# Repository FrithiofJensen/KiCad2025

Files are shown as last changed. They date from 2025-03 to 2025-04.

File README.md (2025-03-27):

# KiCad 2025 - Fra schematic til PCB til ESP-NOW RC System

Velkommen til materialerne for KiCad 2025 seminaret afholdt af Gert Lauritsen. Dette repository indeholder eksempler, projektfiler og Arduino-kode specifikt fokuseret på design af et printkort (PCB) til et fjernstyringssystem (RC) baseret på ESP-NOW protokollen.

Formålet med seminaret er at demonstrere designflowet i KiCad – fra skematisk diagram til færdigt PCB-layout – med et konkret projekt som eksempel: design af hardware til en ESP-NOW baseret sender eller modtager.

Vi vil se på, hvordan man designer et printkort, der integrerer en ESP32 microcontroller sammen med nødvendige komponenter som f.eks. input-enheder (joysticks, knapper) til en sender, eller output-drivere (servo-stik, motor-drivere) til en modtager. De medfølgende `.ino` filer implementerer selve ESP-NOW kommunikationen.

## Indhold

Repository'et indeholder (eller vil indeholde) følgende:

*   **KiCad Projektfiler:**
    *   Eksempler på skematiske diagrammer (`.kicad_sch`) for en RC-sender og/eller modtager.
    *   Eksempler på PCB layouts (`.kicad_pcb`) tilpasset ESP-moduler og RC-komponenter.
    *   Projektfil (`.kicad_pro`).
*   **Biblioteksfiler:**
    *   Specifikke symboler (`.kicad_sym`) og footprints (`.kicad_mod`) brugt i eksemplerne (hvis de ikke er standard i KiCad).
*   **ESP-NOW RC Arduino Sketches (`.ino`):**
    *   `RcRemote.ino`: Kode til ESP32 **senderen**. Læser typisk inputs (f.eks. fra potentiometre/joystick på det designede PCB) og sender data via ESP-NOW.
    *   `RCModtager.ino`: Kode til ESP32 **modtageren**. Modtager data via ESP-NOW og styrer outputs (f.eks. servoer eller motorer, potentielt via det designede PCB).
    *   Disse filer er beregnet til at blive kompileret og uploadet via Arduino IDE til separate ESP32 boards.
*   **Gerber/Produktionsfiler (Eksempel):**
    *   Eksempler på output-filer (`.gbr`, `.drl`) til PCB-produktion.

## Forudsætninger

For at få det fulde udbytte af seminaret og materialerne anbefales følgende software og hardware:

*   **Software:**
    *   **KiCad:**  Den seneste stabile version anbefales. Kan downloades gratis fra [https://www.kicad.org/](https://www.kicad.org/).
    *   **Arduino IDE:** Nødvendig for at arbejde med `.ino` filerne. Kan downloades gratis fra [https://www.arduino.cc/en/software](https://www.arduino.cc/en/software).
        *   **VIGTIGT:** Sørg for at have **ESP8266** og/eller **ESP32 board support** installeret i Arduino IDE via "Boards Manager". Se guides online, f.eks.:
            *   ESP32: [Howto install ESP32](https://randomnerdtutorials.com/installing-esp32-arduino-ide-2-0/)
        *   Tjek `.ino` filerne for eventuelle yderligere nødvendige Arduino libraries (ud over ESP-NOW, som er indbygget) og installer dem via "Library Manager".
*   **Hardware:**
    *   **Mindst to ESP32 boards** (f.eks. NodeMCU, ESP32 DevKitC) – ét til senderen og ét til modtageren for at kunne teste ESP-NOW kommunikationen.
    *   (Valgfrit) Komponenter til at bygge prototyper af sender/modtager (breadboard, ledninger, joysticks, potentiometre, servoer etc.).

## Brug af Materialerne

1.  **Klon eller Download:** Hent materialerne ned på din computer ved at klone repository'et (`git clone https://github.com/gert-lauritsen/KiCad2025.git`) eller downloade det som en ZIP-fil.
2.  **KiCad:** Åbn `.kicad_pro` filen i KiCad for at udforske skematik og PCB layout. Brug filerne som reference eller udgangspunkt for dit eget RC-hardware design.
3.  **Arduino / ESP-NOW:**
    *   Åbn `RcRemote.ino` i Arduino IDE.
    *   Åbn `RCModtager.ino` i et andet Arduino IDE vindue (eller efter hinanden).
    *   **Vigtigt:** ESP-NOW kræver, at enhederne kender hinandens MAC-adresser. Du skal typisk finde MAC-adressen på modtager-boardet og indsætte den i koden på sender-boardet (og/eller omvendt, afhængigt af koden). Find instruktioner til dette i kode-kommentarerne eller i ESP-NOW tutorials.
    *   Vælg det korrekte ESP32 board og port i "Tools" menuen for hvert board.
    *   Kompilér og upload sender-koden til det ene board.
    *   Kompilér og upload modtager-koden til det andet board.
    *   Test kommunikationen. Brug evt. Serial Monitor til debugging.

Vi håber, du får et lærerigt og udbytterigt seminar! Husk at installere KiCad, Arduino IDE og ESP board support *inden* seminaret starter for at få mest muligt ud af det.

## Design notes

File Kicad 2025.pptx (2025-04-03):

## Kicad

Vejen til nemmere PCB design

## Gert Lauritsen

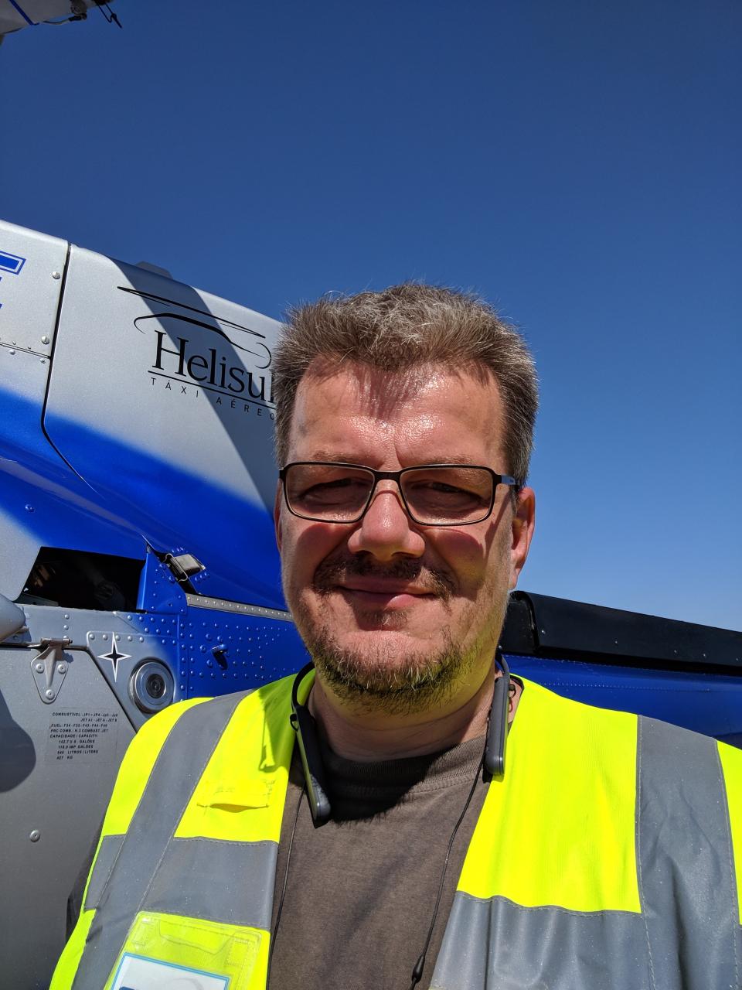
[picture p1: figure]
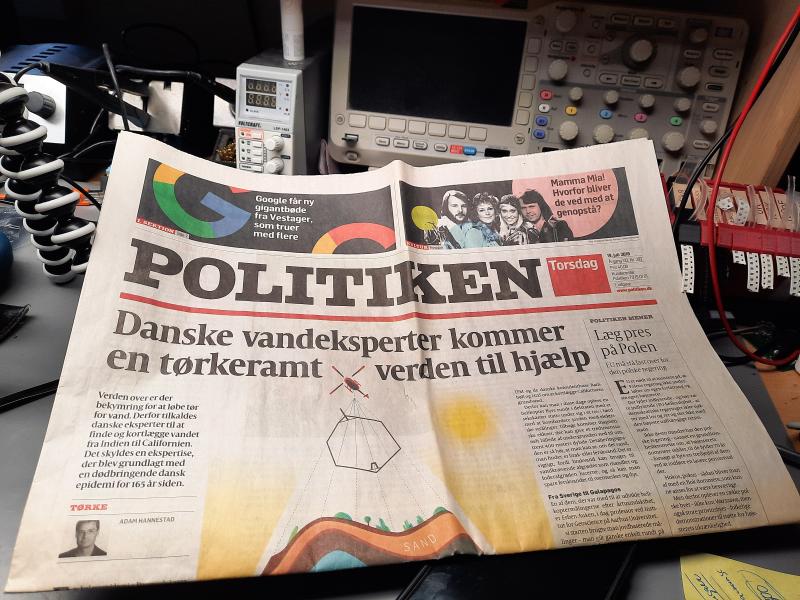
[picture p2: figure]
Et billede, der indeholder tekst, avis, Publikation/tidsskrift/artikel, Avis

- BENG Digital Electronic
- Medskifter af Skytem
- SW&HW udvikler
- Brygger ØL
- 3 børn, kone, hus og Ford

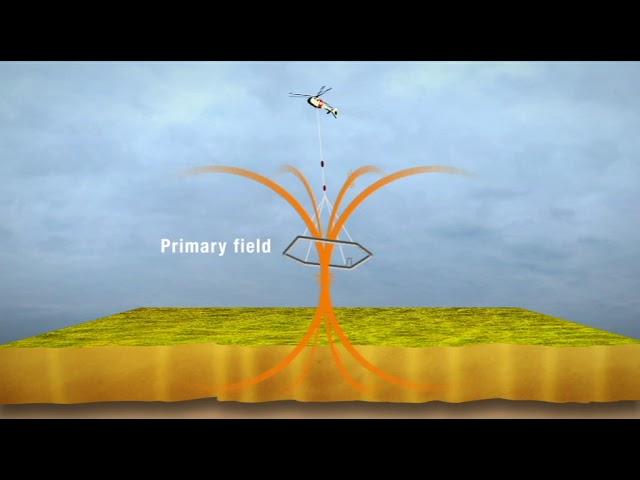
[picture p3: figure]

https://www.youtube.com/watch?v=AwNg--LtuMc

## Agenda

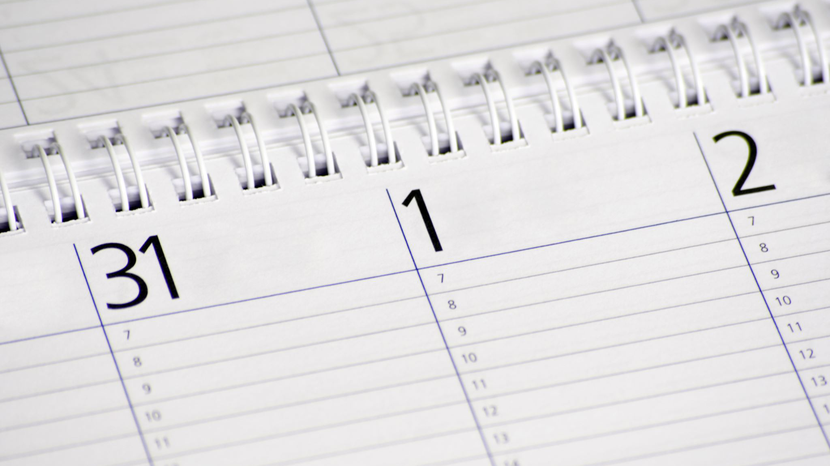
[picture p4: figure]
En side i en planner

- Diagramopsætning
- Gennemgang af fjernbetjenning
- Layout editor
- Gennemgang af Layout
- 3D-visning
- ESP32
  - Serial
  - GPIO
  - ESPnow
  - Gennemgang af RC program

## Åbning af eksistrende projekt

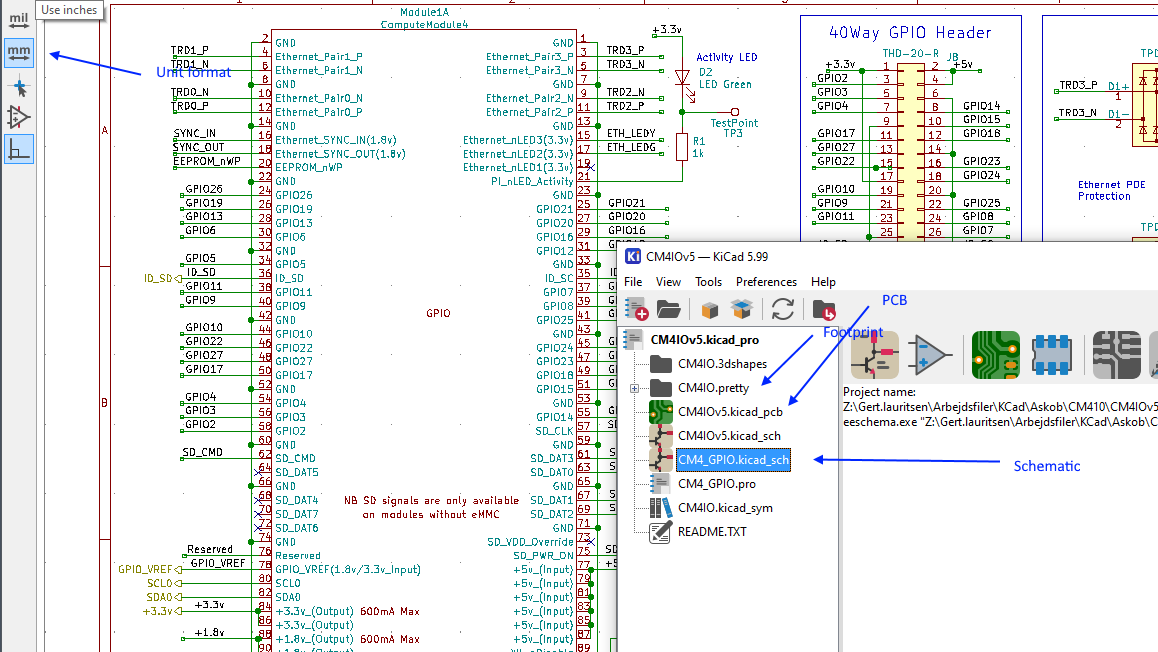
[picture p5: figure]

- Schematic
- PCB

## PlacePart

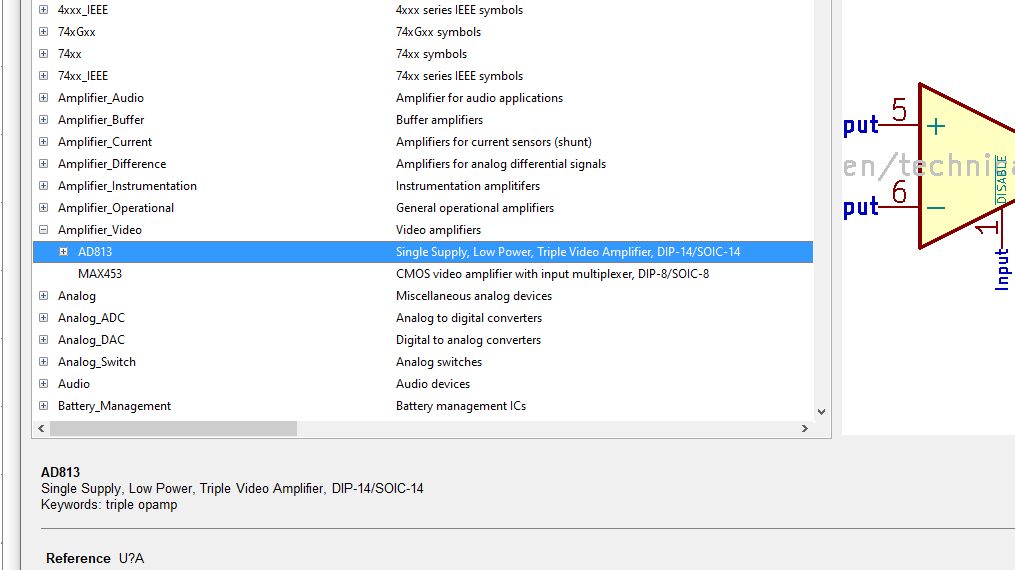
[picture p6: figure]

- Shift+A
- Søg både på part og beskrivelse
- Rotation r/y
- Datablad linket påkomponent
- Part propertry
- Eksterne Library (digikey/mouser)

## Symboler

Power objekter/symboler [P]
Hieraki porte
Globale Nets
Lokale Net
Symboler repræsentere ikke komponeter

## Opgave Tegn følgende skematic

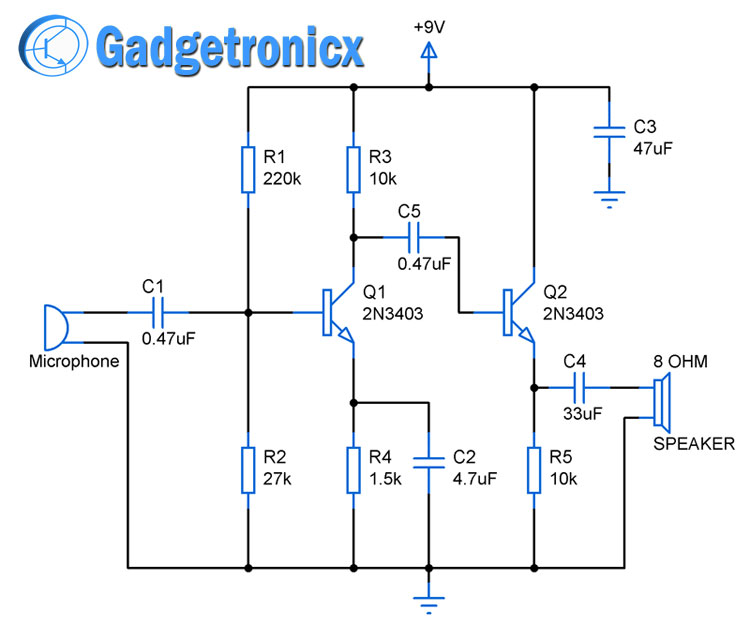
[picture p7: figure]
2-stage-amplifier-circuit-diagram

## Hierarkisk design

- Opret sheet
- Gå ind I sheet
- Export porte

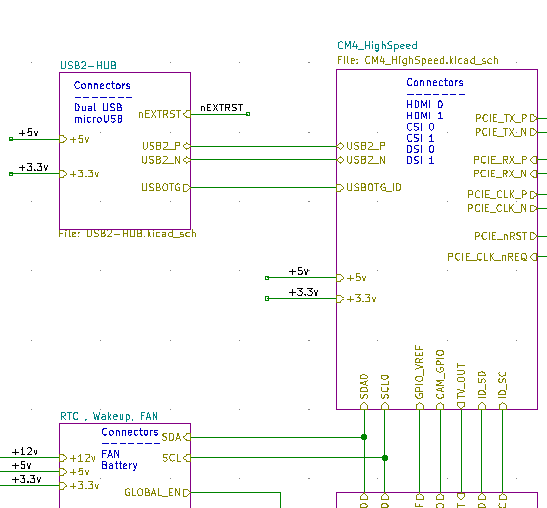
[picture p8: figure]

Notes: Present sensor

## Footprint/netliste

- Annotate
- Place footprint

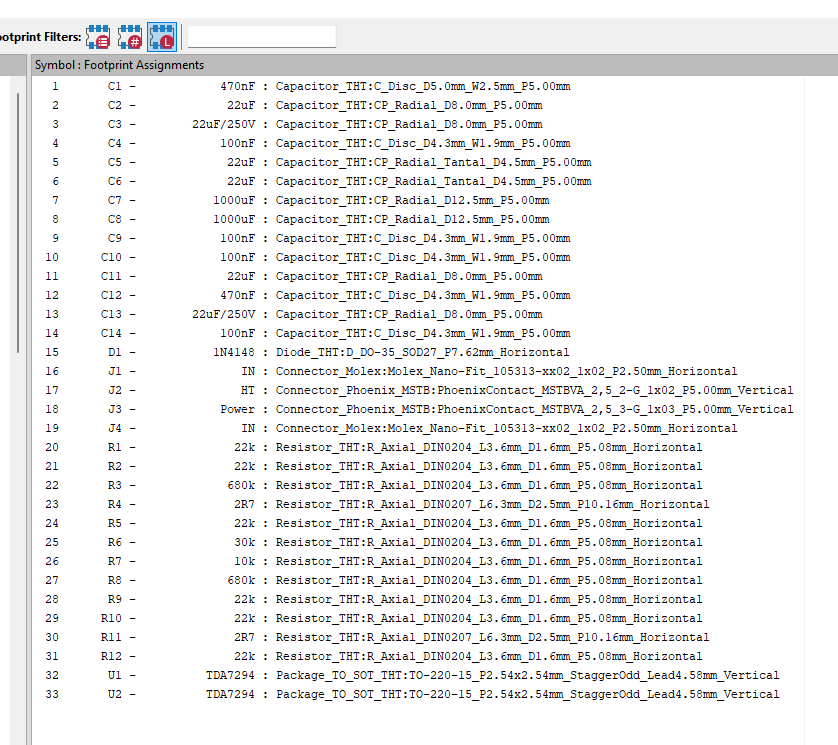
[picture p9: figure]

## Lib Symboler

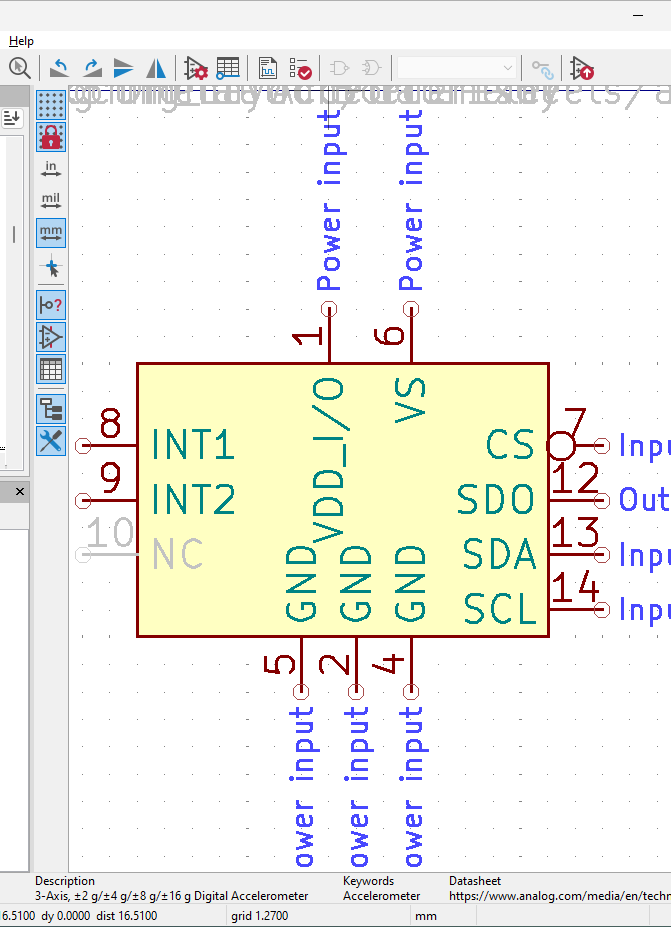
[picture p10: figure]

- Lib Editor

## Layout editor

- Gennemgang af funktioner
- Placement
- Check af footprint

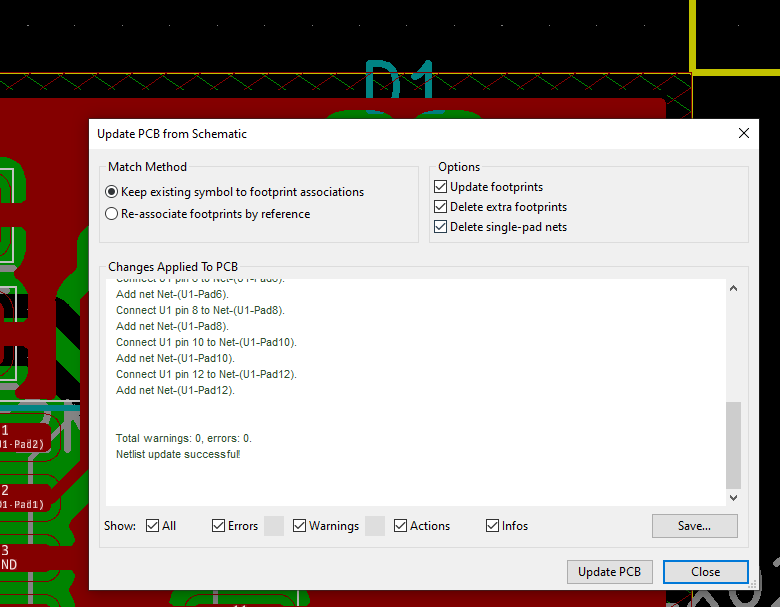
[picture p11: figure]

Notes: Wirenet
Sammenkædning af sch og PCB

## 3D-visning

- Mekanik
- Layer

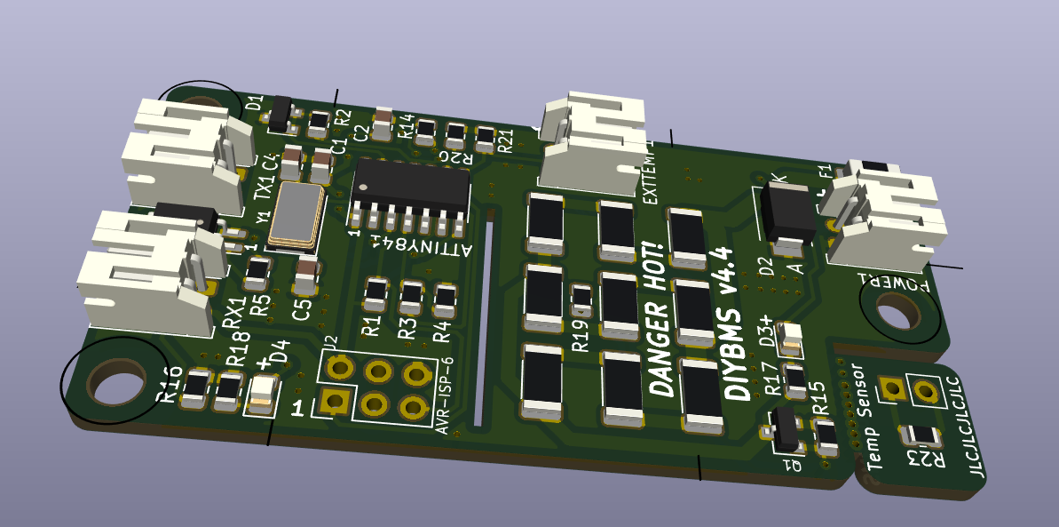
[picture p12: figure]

## Opgave PCB routing

- Route det første schematic til PCB

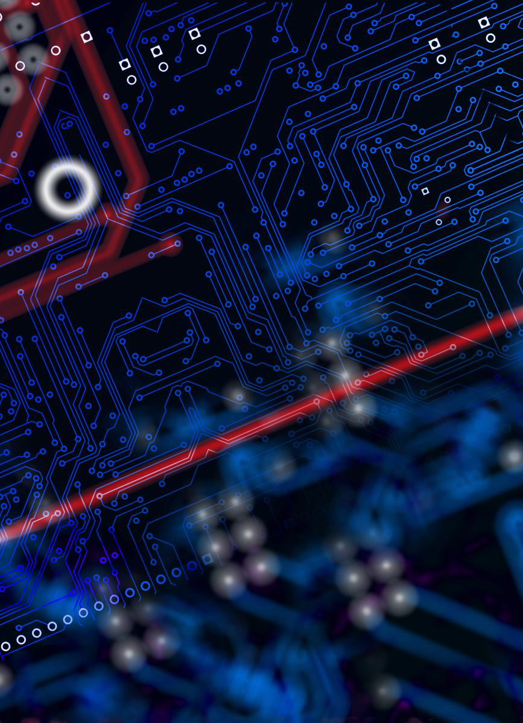
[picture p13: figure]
Elektronisk kredsløbskort

## Hierarkisk Design

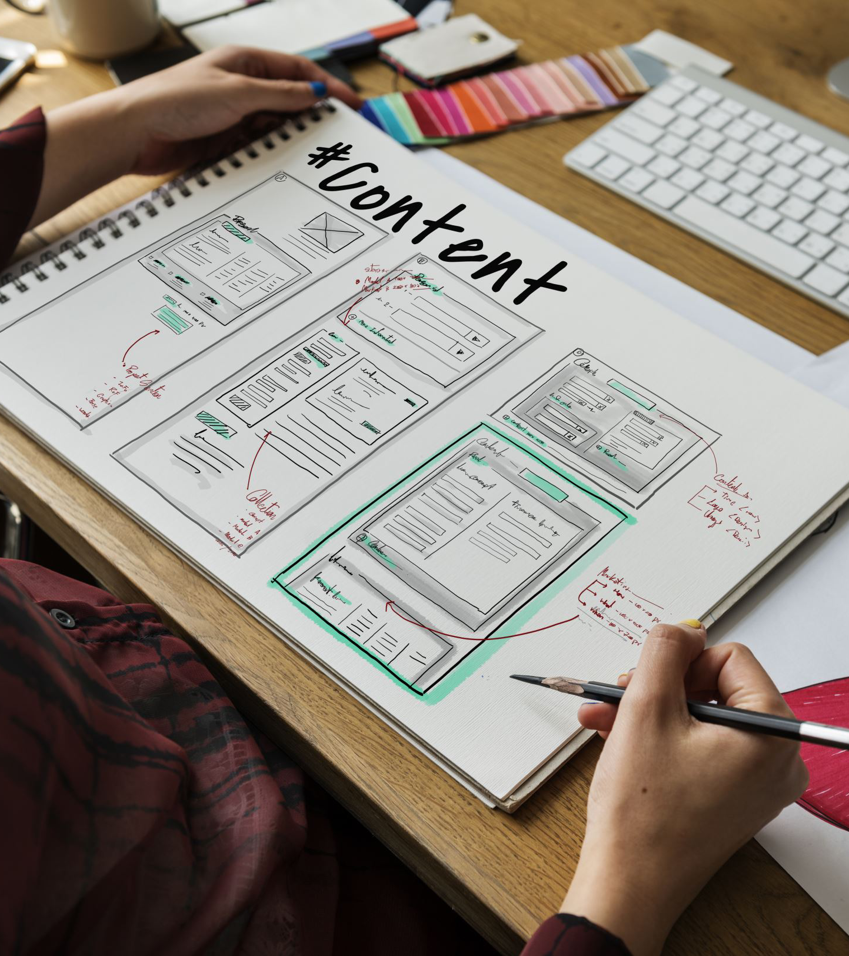
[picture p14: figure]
Person, der skriver i en notesblok

- Hvorfor skal vi tegne hierarksik
  - Class, nedavning, reuse

## Software

Sender/modtager
Serial
GPIO/Analog input
ESPNow
Remote PWM control

## Bootmode

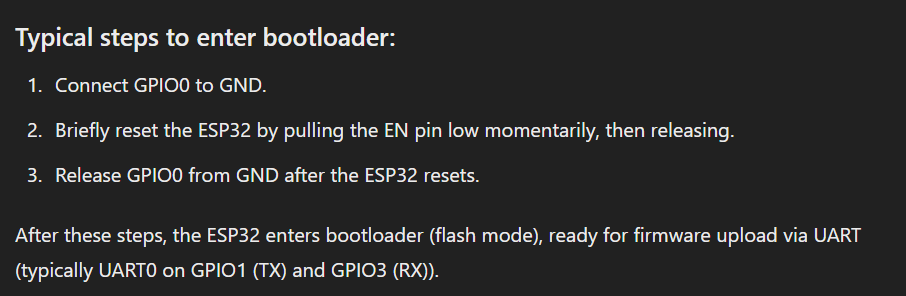
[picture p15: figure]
Et billede, der indeholder tekst, skærmbillede, Font/skrifttype Indhold genereret af kunstig intelligens kan være forkert.
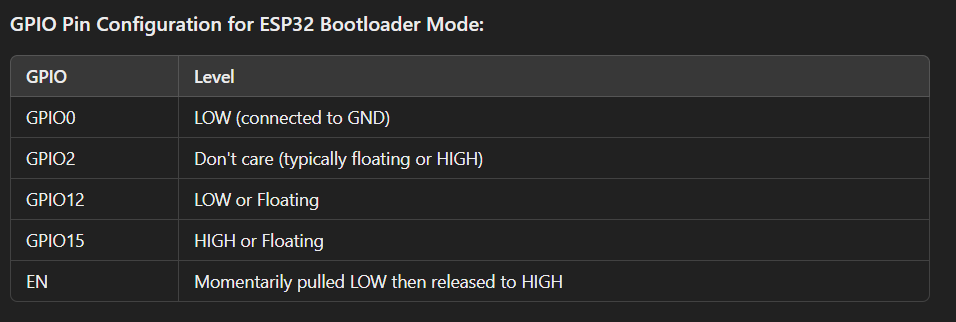
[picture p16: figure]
Et billede, der indeholder tekst, skærmbillede, software, Font/skrifttype Indhold genereret af kunstig intelligens kan være forkert.

## Boot Errors

- PSRAM
- No core dump

E (709) quad_psra: PSRAM ID read error: 0x00ffffff, PSRAM chip not found or not supported

Profil:

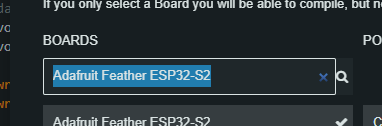
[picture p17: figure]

E (843) esp_core_dump_flash: No core dump partition found!

E (843) esp_core_dump_flash: No core dump partition found!

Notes: https://docs.espressif.com/projects/esptool/en/latest/esp32/advanced-topics/boot-mode-selection.html

## GPIO/Analog input

GPIO - De Digitale Schweizerknive (GPIO: Står for General Purpose Input/Output)
GPIO Funktioner (Primære):
- Digital Input (INPUT):
- Læser en digital tilstand: HØJ (typisk ~3.3V) eller LAV (typisk ~0V / GND).
- Bruges til knapper, simple sensorer (f.eks. bevægelsessensor), signal fra andre enheder.
- Kan ofte konfigureres med INPUT_PULLUP (intern modstand til 3.3V) eller INPUT_PULLDOWN (intern modstand til GND) for at sikre en stabil tilstand, når intet er tilsluttet.
Digital Output (OUTPUT):
- Sætter en digital tilstand: HØJ (3.3V) eller LAV (GND).
- Bruges til at tænde/slukke LEDs, styre relæer (via transistor), sende simple signaler.

## GPIO/Analog input

Analog Input - Måling af Kontinuerlige Værdier
- Hvad er det? Evnen til at måle en kontinuert spænding (inden for et bestemt område) i stedet for kun HØJ/LAV.
ADC: Foregår via en Analog-to-Digital Converter (ADC) indbygget i ESP32.
- Anvendelse: Læsning af potentiometre, lyssensorer (LDR), analoge temperatursensorer, joysticks, etc.
ESP32 ADC Specifikationer:
- Hardware: ESP32 har typisk to ADCs (ADC1 og ADC2).
- Opløsning: Standard er 12-bit. Dette betyder, at ADC'en kan repræsentere spændingen som en digital værdi mellem 0 og 4095.
Arduino IDE Funktioner:
- pinMode(pin, MODE); // Sætter pin til INPUT, OUTPUT, INPUT_PULLUP etc.
- digitalRead(pin); // Læser digital værdi (HIGH/LOW).
- digitalWrite(pin, VALUE); // Skriver digital værdi (HIGH/LOW).
- analogRead(pin); // Læser analog værdi (0-4095).

VIGTIGT: ADC2 & Wi-Fi: Pins tilsluttet ADC2 kan IKKE bruges til analog læsning, mens Wi-Fi er aktivt!
Brug primært pins på ADC1 (f.eks. GPIO 1-10) hvis du også bruger Wi-Fi.
ADC2 finds ikke på ESP32-S2

## ESP Serial Kommunikation (UART)

- Pins: Bruger primært to pins:
- TX (Transmit): Sender data fra ESP'en.
- RX (Receive): Modtager data til ESP'en.
På ESP32 (Arduino IDE):
- Serial Objektet: Standard seriel port, typisk forbundet til USB-porten via en onboard USB-til-UART chip. Bruges til:
- Programmering/Flashing.
- Debugging via Arduino IDE's "Serial Monitor".
- Ekstra Porte (Serial1, Serial2): ESP32 har flere uafhængige hardware UART-porte, som kan mappes til (næsten) valgfri GPIO pins til kommunikation med andre enheder (sensorer, GPS, osv.).
Vigtige Funktioner:
- Serial.begin(baud_rate); // Starter kommunikationen med specificeret hastighed.
- Serial.print("Tekst"); // Sender tekst.
- Serial.println(value); // Sender værdi og linjeskift.
- Serial.available(); // Tjekker om der er data klar til at blive læst.
- Serial.read(); // Læser ét byte af modtaget data.
Typiske Anvendelser:
✅ Debugging: Nemmeste måde at få information ud fra din ESP32 under kørsel.
✅ Programmering: Standardmetoden til at uploade kode.
✅ Kommunikation med PC: Simple kontrol-interfaces eller dataopsamling.
✅ Kommunikation med Perifere Enheder: GPS moduler, visse sensorer, andre microcontrollere.

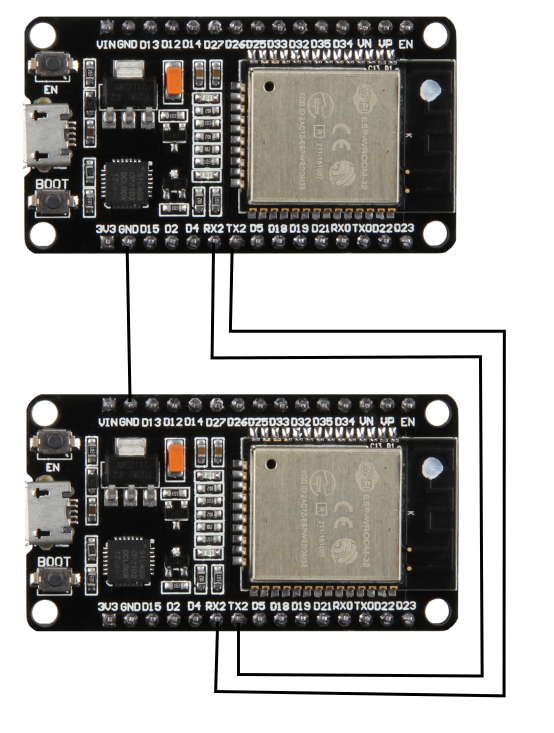
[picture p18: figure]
Problems with using Serial2 communication between 2 esp32 - Programming - Arduino Forum

## Serial Opgave

- Få din ESP32 til at skrive klokken.
- Hvis der er tid, så connect til NTP
- // --- NTP Settings --- const char* ntpServer1 = "pool.ntp.org"; const char* ntpServer2 = "time.nist.gov"; // Optional backup server

## ESPNow

Hvad er ESP-NOW?
- En kommunikationsprotokol udviklet af Espressif (firmaet bag ESP32/ESP8266).
- Tillader direkte (peer-to-peer) kommunikation mellem ESP-enheder.
- Bruger ikke et traditionelt Wi-Fi netværk (ingen router/AP nødvendig).
Hvordan Virker Det?
- MAC Adresser: Enheder identificerer hinanden vha. deres unikke MAC-adresse (ligesom et "device ID").
- Forbindelsesløs: Sender data uden først at etablere en formel forbindelse (ligesom UDP, men simplere). Ingen "handshake".
- Korte Pakker: Sender små datapakker (op til 250 bytes).
- Callbacks: Bruger funktioner (callbacks) til at vide, hvornår data er sendt succesfuldt, eller hvornår data er modtaget.
Vigtigste Fordele:
- ✅ Hurtigt: Meget lav forsinkelse (latency) – data sendes næsten øjeblikkeligt.
- ✅ Lavt Strømforbrug: Effektivt, da der ikke opretholdes en konstant Wi-Fi forbindelse. Godt til batteridrevne enheder.
- ✅ Simpelt: Nemmere at sætte op end fuld Wi-Fi-forbindelse eller Bluetooth.
- ✅ Pålideligt (kort afstand): God til stabil kommunikation over korte afstande.
Begrænsninger:
- Kort Rækkevidde: Ligesom almindelig Wi-Fi (typisk < 100m, afhængigt af omgivelser).
- Ikke Routbart: Kan ikke sende data direkte over internettet (kræver en "gateway" ESP, der er på Wi-Fi/Ethernet).
- Begrænset Data: Kun små datapakker ad gangen (max 250 bytes).
- Kun ESP: Virker kun mellem Espressif-chips (ESP32, ESP8266).
Typiske Anvendelser:
- Sensornetværk (mange sensorer sender til én central enhed).
- Fjernbetjeninger og trådløse knapper.
- Hurtig udveksling af status mellem enheder.
- Enkel styring af lys, relæer osv.
Konklusion:
ESP-NOW er ideelt til hurtig, lokal og strømbesparende kommunikation mellem ESP-enheder, hvor der ikke er behov for et fuldt Wi-Fi netværk eller internetadgang.

## ESPNow opgave

- Send et signal til din side maker, som tænder og slukker hans LED 1 gang/sekund
- Det må kun sendes til hans MAC adresse og ikke andre.
- Den anden laver modtageren

## Remote PWM control

Hvad er RC PWM?
- RC: Står for Radio Control (typisk brugt i hobby-modeller).
- PWM: Pulse Width Modulation. En digital måde at repræsentere en analog værdi (f.eks. en position eller hastighed).
- RC PWM: En specifik type PWM-signal, der er standard inden for RC-hobbyen til at styre komponenter.
Hvordan Virker Det?
- Gentagende Puls: Signalet består af en puls, der gentages med en fast frekvens, typisk 50 Hz (dvs. én puls hvert 20. millisekund).
- Pulsens Bredde (Varighed): Det vigtige er, hvor længe pulsen er "høj" (typisk 3.3V eller 5V) inden for hver 20 ms cyklus. Denne varighed måles i mikrosekunder (µs).
Betydningen af Bredden:
- ~1000 µs (1.0 ms): Typisk minimum værdi (f.eks. servo helt til venstre, motor slukket).
- ~1500 µs (1.5 ms): Typisk center/neutral værdi (f.eks. servo i midten, motor stoppet/neutral).
- ~2000 µs (2.0 ms): Typisk maksimum værdi (f.eks. servo helt til højre, motor fuld gas).
Typiske Anvendelser:
- Servo Motorer: Pulsbredden bestemmer den vinkel, servoen skal dreje til.
- Electronic Speed Controllers (ESC'er): Pulsbredden bestemmer den hastighed (og retning), motoren skal køre med.

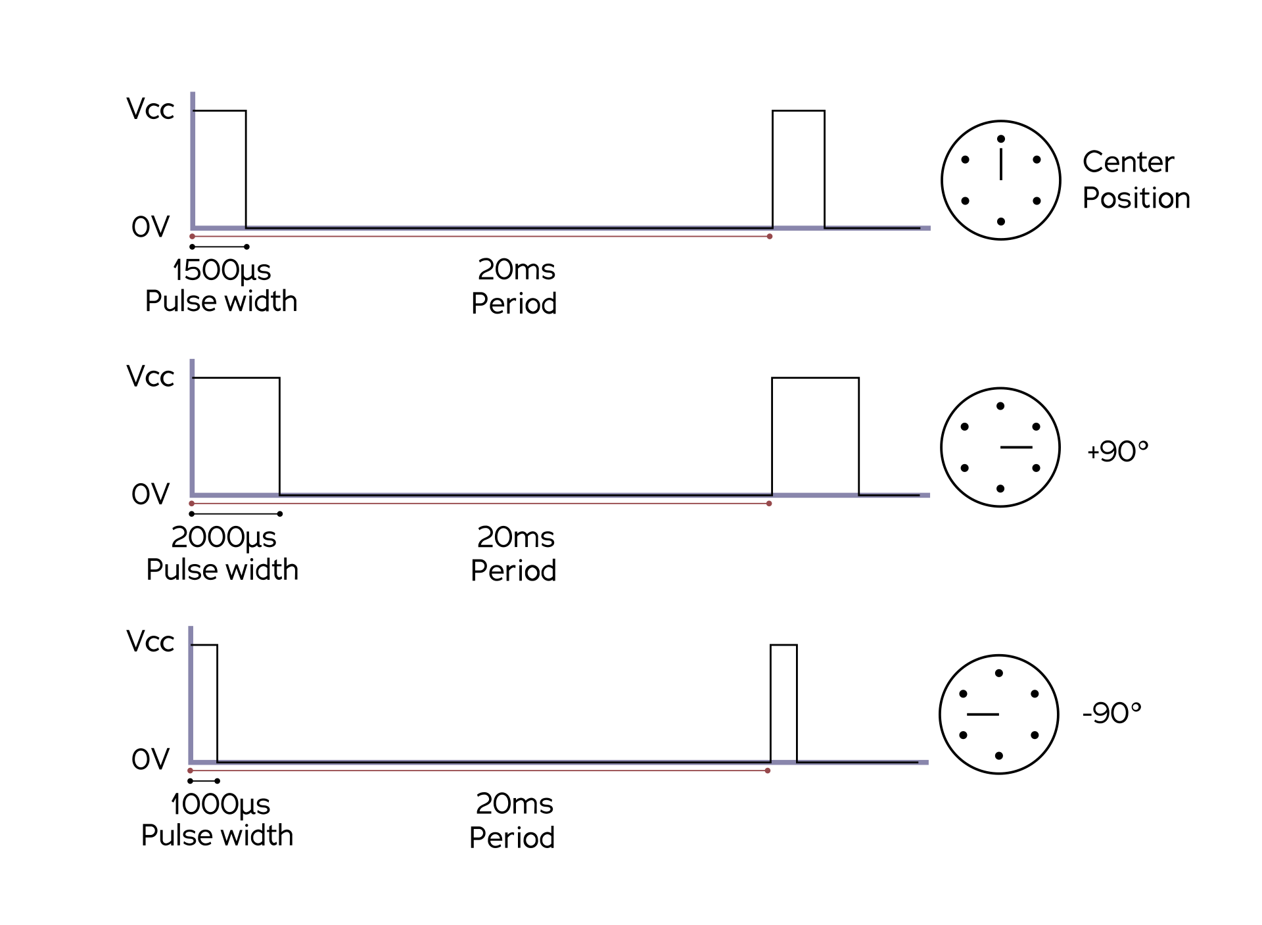
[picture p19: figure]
undefined

## Kina logik

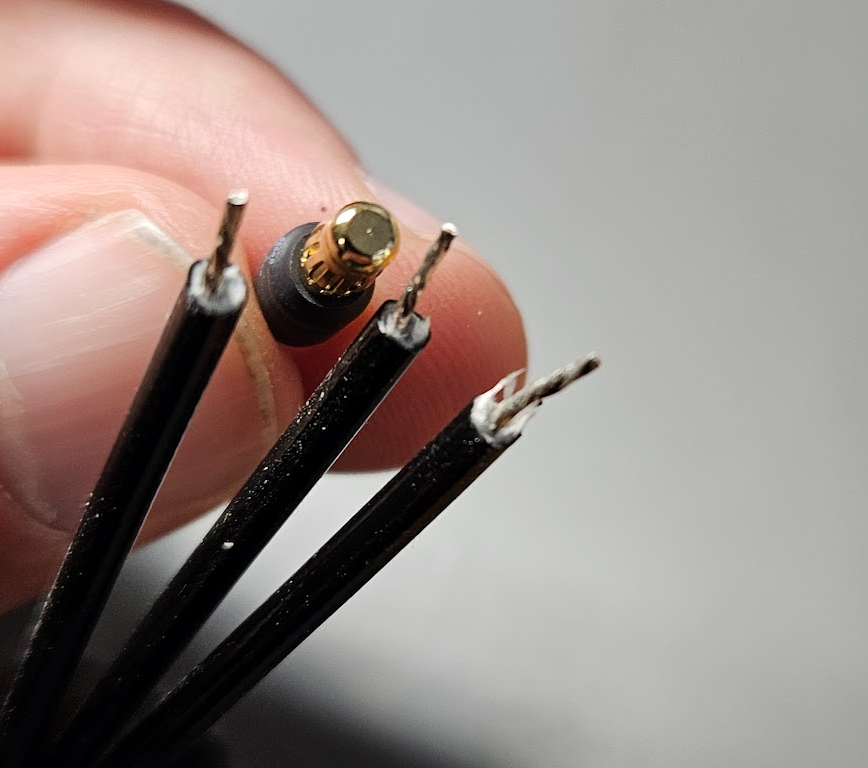
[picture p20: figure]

## Gennemgang af RC sender

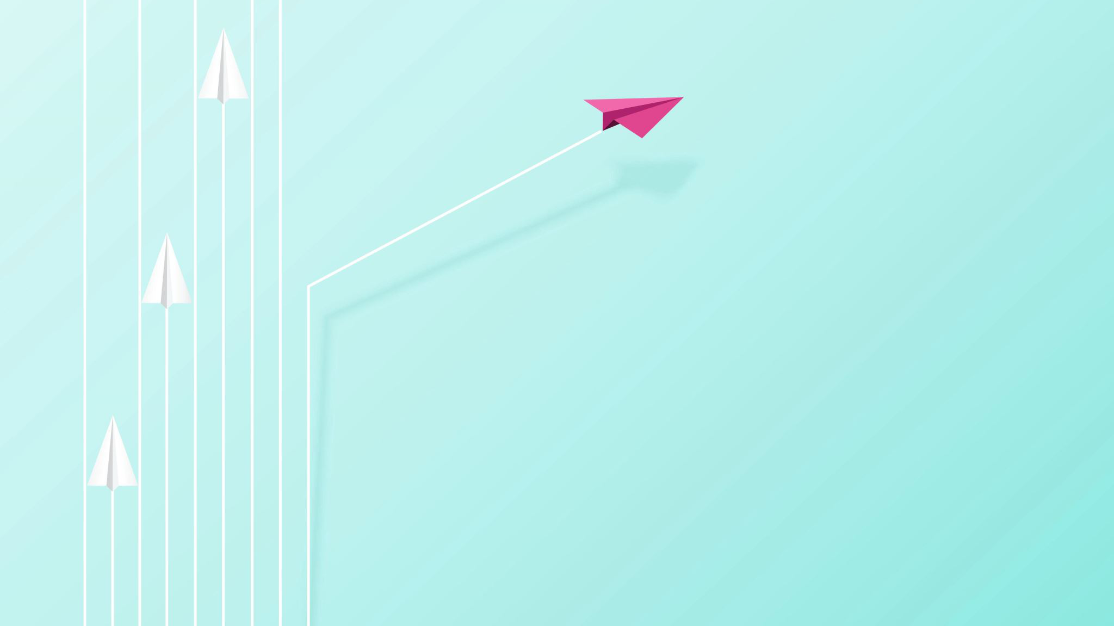
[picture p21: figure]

## Gennemgang af RC modtager

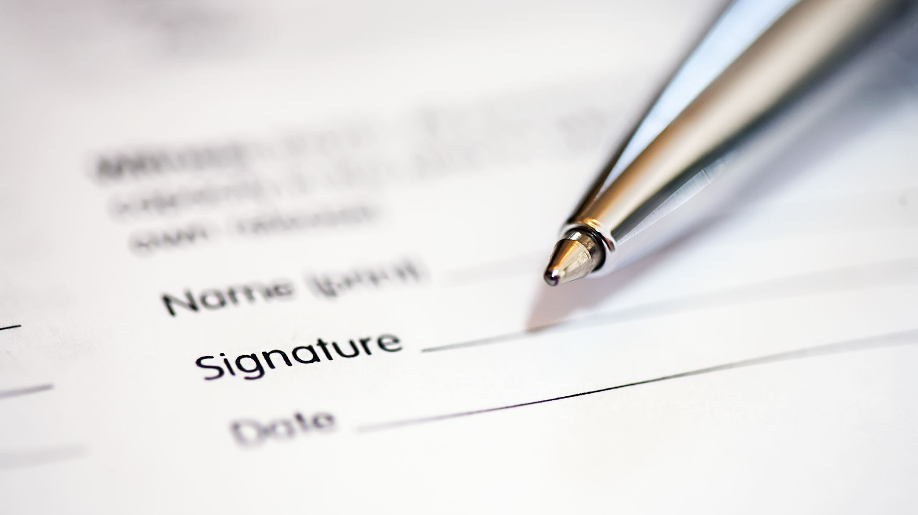
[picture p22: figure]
Pen, der er placeret oven på en signaturlinje

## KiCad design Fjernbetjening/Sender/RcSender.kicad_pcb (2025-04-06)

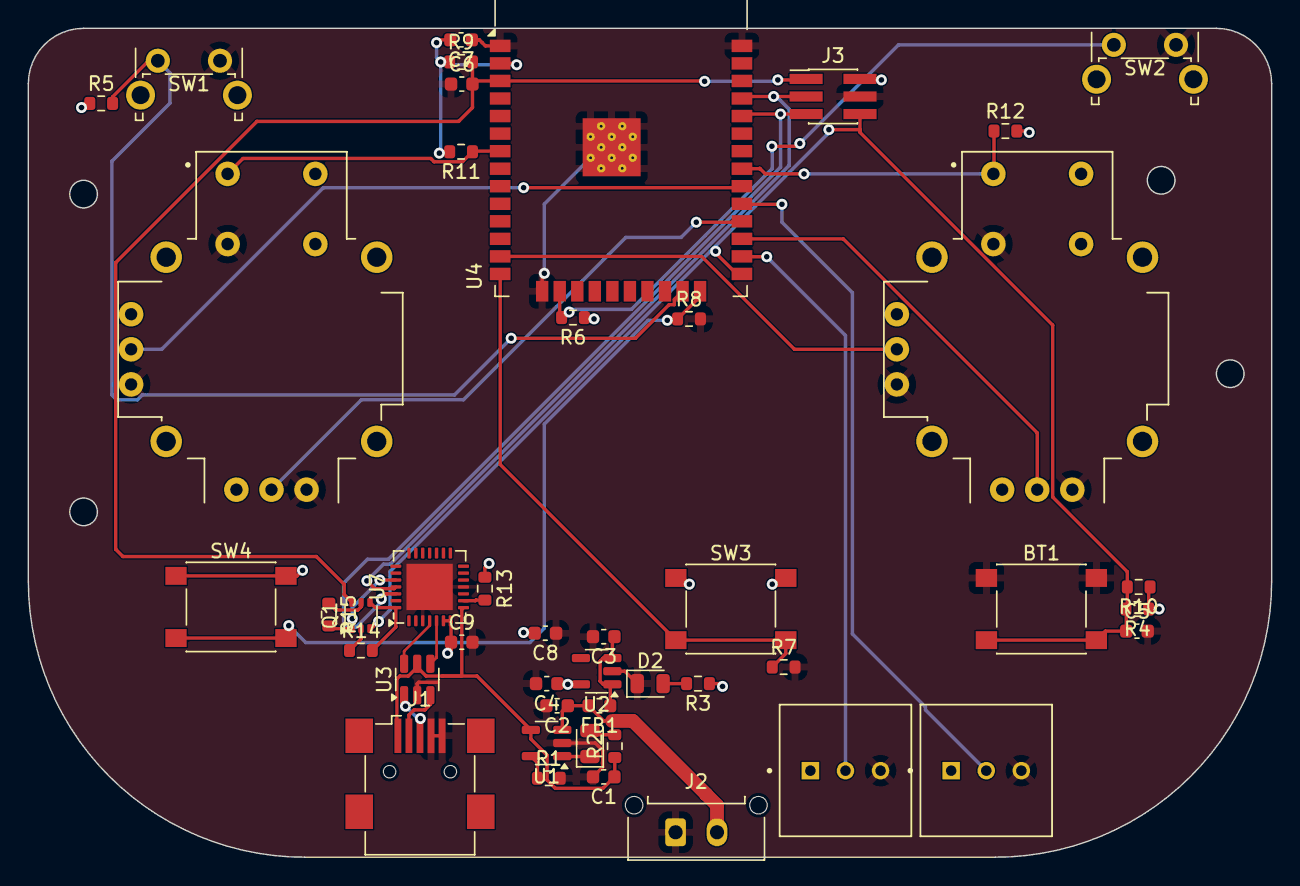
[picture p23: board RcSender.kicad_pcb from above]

Board: 2 copper layers, 90.0 x 60.0 mm, 45 parts (0 on the bottom side), 34 nets.

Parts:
BT1: SW_Push; SW_SPST_PTS645
C1, C3, C4: 1uF; C_0603_1608Metric
C2: 10nF; C_0603_1608Metric
C5, C6, C7, C8: 0.1uf; C_0603_1608Metric
C9: 10u; C_0603_1608Metric
D1: Chrg; LED_0805_2012Metric
D2: PWR ON; LED_0805_2012Metric
FB1: Ferrite Bead; L_0603_1608Metric
J1: USB_A; USB_Mini-B_Wuerth_65100516121_Horizontal
J2: Bat; Molex_Micro-Fit_3.0_43650-0215_1x02_P3.00mm_Vertical
J3: Prog; PinHeader_2x03_P1.27mm_Vertical_SMD
POT1, POT2: COM-09806; POT-COM_09806
Q1: BC846BS; SOT-363_SC-70-6
R1: 2k; R_0603_1608Metric
R2, R3: 330; R_0603_1608Metric
R4, R5, R6, R7, R8, R11, R12: 4.7k; R_0603_1608Metric
R9, R10: 10K; R_0603_1608Metric
R13: 1k; R_0603_1608Metric
R14, R15: 10k; R_0603_1608Metric
SW1, SW2: SW_Push; SW_Tactile_SPST_Angled_PTS645Vx39-2LFS
SW3, SW4: SW_Push; SW_SPST_PTS645
U1: MCP73832-2-OT; SOT-23-5
U2: AP2112K-3.3; SOT-23-5
U3: USBLC6-2SC6; SOT-23-6
U4: ESP32-WROOM-32
U5, U6: COM-09032; POT-COM-09032
U7: CP2102N-Axx-xQFN28; QFN-28-1EP_5x5mm_P0.5mm_EP3.35x3.35mm

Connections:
+3.3V: C4.1, C7.2, C8.2, C9.1, J3.2, POT1.1, POT2.1, R3.1, R4.1, R5.1, R6.1, R9.1, R10.1, R11.2, R12.2, R13.1, SW3.1, SW4.1, U2.5 (VOUT), U4.2 (VDD), U5.H1 (H+), U5.V1 (V+), U6.H1 (H+), U6.V1 (V+), U7.6 (VDD), U7.7 (VREGIN)
+5V: C1.1, J1.1 (VBUS), R2.1, U1.4 (V_{DD}), U3.5 (VBUS), U7.8 (VBUS)
BT: BT1.2, C5.1, J3.6, Q1.3 (C2), R4.2, R10.2, U4.25 (IO0)
EN: C6.2, J3.1, Q1.6 (C1), R9.2, U4.3 (EN)
GND: BT1.1, C1.2, C2.2, C3.2, C4.2, C5.2, C6.1, C7.1, C8.1, C9.2, D2.1 (K), J1.4 (GND), J1.5 (Shield), J2.1, J3.4, POT1.3, POT2.3, R1.2, R7.2, R8.2, SW1.2, SW2.2, U1.2 (V_{SS}), U2.2 (GND), U3.2 (GND), U4.1 (GND), U4.15 (GND), U4.38 (GND), U4.39 (GND), U5.B2A (SEL-), U5.H3 (H-), U5.V3 (V-), U6.B2A (SEL-), U6.H3 (H-), U6.V3 (V-), U7.3 (GND), U7.11 (~SUSPEND), U7.29 (GND)
IO2: R8.1, SW4.2, U4.24 (IO2)
IO4: POT2.2, U4.26 (IO4)
IO5: POT1.2, U4.29 (IO5)
IO12: R7.1, SW3.2, U4.14 (IO12)
IO13: R6.2, SW2.1, U4.16 (IO13)
IO14: U4.13 (IO14), U6.V2 (V)
IO15: R5.2, SW1.1, U4.23 (IO15)
IO16: U4.27 (IO16), U6.H2 (H)
IO17: U4.28 (IO17), U5.H2 (H)
IO18: U4.30 (IO18), U5.V2 (V)
IO19: R12.1, U4.31 (IO19), U6.B1A (SEL+)
IO35: R11.1, U4.7 (IO35), U5.B1A (SEL+)
unnamed: D1.2 (A), R2.2
unnamed: D1.1 (K), U1.1 (STAT)
unnamed: D2.2 (A), R3.2
unnamed: J1.3 (D+), U3.1 (I/O1)
unnamed: J1.2 (D-), U3.3 (I/O2)
unnamed: Q1.2 (B1), R14.1
unnamed: Q1.1 (E1), R15.2, U7.24 (~RTS)
unnamed: Q1.5 (B2), R15.1
unnamed: Q1.4 (E2), R14.2, U7.28 (~DTR)
unnamed: R1.1, U1.5 (PROG)
unnamed: C3.1, FB1.1, U2.1 (VIN), U2.3 (EN)
unnamed: R13.2, U7.9 (~RST)
RX: J3.5, U4.34 (RXD0/IO3), U7.26 (TXD)
TX: J3.3, U4.35 (TXD0/IO1), U7.25 (RXD)
USBN: U3.4 (I/O2), U7.5 (D-)
USBP: U3.6 (I/O1), U7.4 (D+)
VIN: C2.1, FB1.2, J2.2, U1.3 (V_{BAT})

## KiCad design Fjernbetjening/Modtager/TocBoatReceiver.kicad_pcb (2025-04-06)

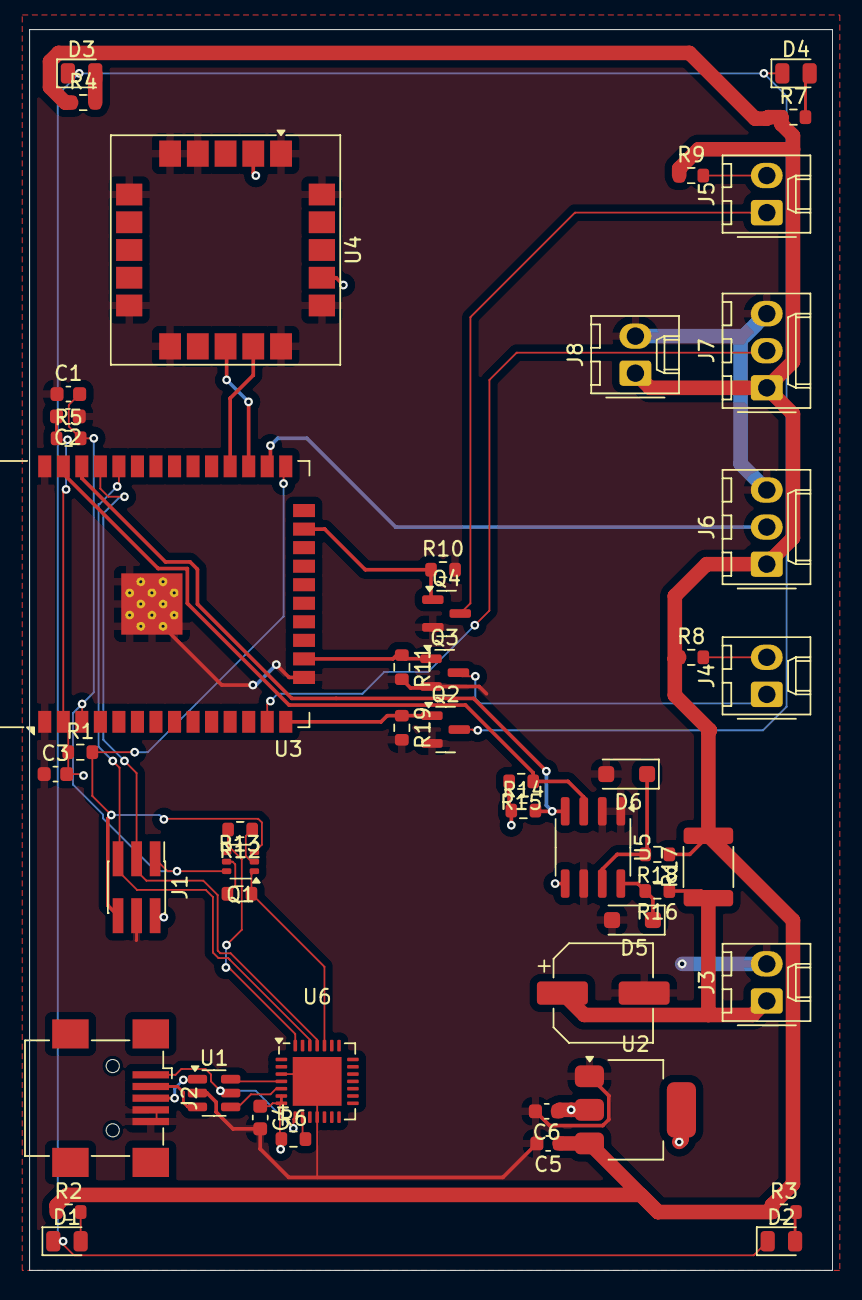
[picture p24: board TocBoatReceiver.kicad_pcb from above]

Board: 2 copper layers, 55.0 x 85.0 mm, 50 parts (0 on the bottom side), 38 nets.

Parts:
C1, C2, C3: 0.1uf; C_0603_1608Metric
C4: 10u; C_0603_1608Metric
C5, C6: 1u; C_0603_1608Metric
C7: 100uF; CP_Elec_6.3x5.4
D1, D2, D3, D4: LED; LED_0805_2012Metric
D5, D6: BZT52B-C20; D_SOD-123F
J1: Prog; PinHeader_2x03_P1.27mm_Vertical_SMD
J2: USB_A; USB_Mini-B_Wuerth_65100516121_Horizontal
J3: Battery; Molex_KK-254_AE-6410-02A_1x02_P2.54mm_Vertical
J4, J5: Conn_01x02; Molex_KK-254_AE-6410-02A_1x02_P2.54mm_Vertical
J6: SpeedController; Molex_KK-254_AE-6410-03A_1x03_P2.54mm_Vertical
J7: Servo; Molex_KK-254_AE-6410-03A_1x03_P2.54mm_Vertical
J8: PowerESC; Molex_KK-254_AE-6410-02A_1x02_P2.54mm_Vertical
Q1: BC846BS; SOT-363_SC-70-6
Q2, Q3, Q4: AO3400A; SOT-23
R1, R5, R10, R11, R14, R15, R19: 10K; R_0603_1608Metric
R2, R3, R4, R6, R7, R8, R9: 1k; R_0603_1608Metric
R12, R13: 10k; R_0603_1608Metric
R16, R18: 100; R_0603_1608Metric
R17: 0.01R; R_1812_4532Metric
U1: USBLC6-2SC6; SOT-23-6
U2: AP1117-33; SOT-223-3_TabPin2
U3: ESP32-WROOM-32
U4: SAM-M8Q; ublox_SAM-M8Q
U5: INA219BxD; SOIC-8_3.9x4.9mm_P1.27mm
U6: CP2102N-Axx-xQFN28; QFN-28-1EP_5x5mm_P0.5mm_EP3.35x3.35mm

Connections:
+3.3V: C2.2, C3.2, C4.1, C6.1, J1.2, R1.1, R5.1, R6.1, R14.1, R15.2, U2.2 (VO), U3.2 (VDD), U4.2 (VCC_IO), U4.17 (VCC), U5.5 (VS), U6.6 (VDD), U6.7 (VREGIN)
+5V: J2.1 (VBUS), U1.5 (VBUS), U6.8 (VBUS)
+BATT: C5.1, J6.1, J7.1, J8.1, R2.1, R3.1, R4.1, R7.1, R8.1, R9.1, R17.2, R18.1, U2.3 (VI)
/ESP32/GPIO4: J6.2, U3.26 (IO4)
/ESP32/GPIO12: Q2.1 (G), R19.1, U3.14 (IO12)
/ESP32/GPIO13: Q3.1 (G), R11.1, U3.16 (IO13)
/ESP32/GPIO14: J7.2, U3.13 (IO14)
/ESP32/GPIO15: Q4.1 (G), R10.1, U3.23 (IO15)
/ESP32/GPIO16: U3.27 (IO16), U4.13 (TXD)
/ESP32/GPIO17: U3.28 (IO17), U4.14 (RXD)
/ESP32/SCL: R14.2, U3.36 (IO22), U5.4 (SCL)
/ESP32/SDA: R15.1, U3.37 (IO23), U5.3 (SDA)
/USB Serial/USB_N: U1.4 (I/O2), U6.5 (D-)
/USB Serial/USB_P: U1.6 (I/O1), U6.4 (D+)
D0: J1.6, Q1.3 (C2), R1.2, U3.25 (IO0)
EN: C1.2, J1.1, Q1.6 (C1), R5.2, U3.3 (EN)
GND: C1.1, C2.1, C3.1, C4.2, C5.2, C6.2, C7.2, D5.2 (A), D6.2 (A), J1.4, J2.4 (GND), J2.5 (Shield), J3.2, J6.3, J7.3, J8.2, Q2.2 (S), Q3.2 (S), Q4.2 (S), R10.2, R11.2, R19.2, U1.2 (GND), U2.1 (GND), U3.1 (GND), U3.15 (GND), U3.38 (GND), U3.39 (GND), U4.1 (GND), U4.4 (GND), U4.5 (GND), U4.6 (GND), U4.10 (GND), U4.11 (GND), U4.15 (GND), U4.16 (GND), U4.20 (GND), U5.1 (A1), U5.2 (A0), U5.6 (GND), U6.3 (GND), U6.11 (~SUSPEND), U6.29 (GND)
unnamed: D1.2 (A), R2.2
unnamed: D1.1 (K), D2.1 (K), D3.1 (K), D4.1 (K), Q2.3 (D)
unnamed: D2.2 (A), R3.2
unnamed: D3.2 (A), R4.2
unnamed: D4.2 (A), R7.2
unnamed: D5.1 (K), R16.2, U5.8 (IN+)
unnamed: D6.1 (K), R18.2, U5.7 (IN-)
unnamed: J2.3 (D+), U1.1 (I/O1)
unnamed: J2.2 (D-), U1.3 (I/O2)
unnamed: C7.1, J3.1, R16.1, R17.1
unnamed: J4.1, Q3.3 (D)
unnamed: J4.2, R8.2
unnamed: J5.1, Q4.3 (D)
unnamed: J5.2, R9.2
unnamed: Q1.2 (B1), R12.1
unnamed: Q1.1 (E1), R13.2, U6.24 (~RTS)
unnamed: Q1.5 (B2), R13.1
unnamed: Q1.4 (E2), R12.2, U6.28 (~DTR)
unnamed: R6.2, U6.9 (~RST)
RX: J1.5, U3.34 (RXD0/IO3), U6.26 (TXD)
TX: J1.3, U3.35 (TXD0/IO1), U6.25 (RXD)

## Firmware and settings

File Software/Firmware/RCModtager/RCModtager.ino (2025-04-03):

#include <esp_now.h>
#include <WiFi.h>
#include <Arduino.h>
#include <ESP32Servo.h>

#define MotorESC 16
#define RorServo 14

// --- Configuration ---
// Define pin counts (must match sender)
const int numPots = 4;
const int numSwitches = 7;
const int minThrottle = 1100; // Don't go below 1000 µs
const int maxThrottle = 2400; // Your maximum value

// Define dead-zone threshold
const int DEAD_ZONE_THRESHOLD = 5100;

// --- Data Structure ---
// Structure to hold sensor data. MUST match the sender's structure.
typedef struct SensorData {
  uint16_t potValues[numPots];
  bool switchStates[numSwitches];
} SensorData;

// Create an instance of the structure to store received data
SensorData receivedData;
bool LastswitchStates[numSwitches];
bool outputs[numSwitches];

Servo servo1;  // Servo on GPIO 14
Servo servo2;  // Servo on GPIO 16

void UpdateOutput() {
  //maps switchs to outputs
  digitalWrite(15,outputs[0]);
  digitalWrite(17,outputs[1]);
  digitalWrite(18,outputs[2]);
}


void UpdateServo(){
    // Update servo positions based on potValues (assuming 0-8192 input range)
  int servoAngle1 = map(receivedData.potValues[1], DEAD_ZONE_THRESHOLD, 8192, minThrottle, maxThrottle);
  int servoAngle2 = map(receivedData.potValues[0], 0, 8192, 0, 180);

  servo1.writeMicroseconds(servoAngle1);
  servo2.write(servoAngle2);
  for (int i = 0; i < numPots; i++) {
    if (receivedData.switchStates[i] && (!LastswitchStates[i])) {
      outputs[i] = !outputs[i];
    }
    LastswitchStates[i]=receivedData.switchStates[i];
  } 
  UpdateOutput(); 
}


// --- Callback Function ---
// Function called when data is received
//void OnDataRecv(const uint8_t *mac_addr, const uint8_t *incomingData, int len) {
void OnDataRecv(const esp_now_recv_info_t *recv_info, const uint8_t *incomingData, int len) {
  //const uint8_t *mac_addr = recv_info->src_addr;
  // Check if the data length matches the structure size
  if (len == sizeof(receivedData)) {
    memcpy(&receivedData, incomingData, sizeof(receivedData));

    // Print received data to Serial Monitor
    Serial.println("--- Received Data ---");

    // Print Potentiometer Values
    Serial.print("Pots: ");
    for (int i = 0; i < numPots; i++) {
      Serial.print(receivedData.potValues[i]);
      if (i < numPots - 1) Serial.print(", ");
    }
    Serial.println(); // New line after pots

    // Print Switch States
    Serial.print("Switches: ");
    for (int i = 0; i < numSwitches; i++) {
      Serial.print(receivedData.switchStates[i] ? "ON" : "OFF"); // Print ON/OFF for clarity
      // Or just print 1/0: Serial.print(receivedData.switchStates[i]);
      if (i < numSwitches - 1) Serial.print(", ");
    }
    Serial.println(); // New line after switches
    Serial.println("---------------------");
    UpdateServo(); //Send data to servo
  } else {
    Serial.print("Received data of incorrect size: ");
    Serial.print(len);
    Serial.print(" expected: ");
    Serial.println(sizeof(receivedData));
  }

}

// --- Setup Function ---
void setup() {
  Serial.begin(115200);
  Serial.println("ESP32 ESP-NOW Receiver");

  // 1. Set device as a Wi-Fi Station
  WiFi.mode(WIFI_STA);
  Serial.print("Receiver MAC Address: ");
  Serial.println(WiFi.macAddress()); // Print this MAC address!

  // 2. Initialize ESP-NOW
  if (esp_now_init() != ESP_OK) {
    Serial.println("Error initializing ESP-NOW");
    return;
  }
  Serial.println("ESP-NOW Initialized.");
    // Allow allocation of GPIO pins for ESP32 Servo control
  ESP32PWM::allocateTimer(0);
  ESP32PWM::allocateTimer(1);
  ESP32PWM::allocateTimer(2);
  ESP32PWM::allocateTimer(3);

  servo1.setPeriodHertz(50); // standard 50 Hz servo
  servo2.setPeriodHertz(50);

  // Servo initialization

  servo1.attach(MotorESC);
  servo2.attach(RorServo);
  servo1.writeMicroseconds(minThrottle);  // Initialize ESC at 0 throttle
  delay(5000); // Wait 5 seconds for ESC to arm
  // GPIO outputs initialization
  pinMode(15, OUTPUT);
  pinMode(17, OUTPUT);
  pinMode(18, OUTPUT);

  // 3. Register the receive callback function
  esp_now_register_recv_cb(OnDataRecv);
  Serial.println("Receive Callback Registered.");
  Serial.println("Setup Complete. Waiting for data...");
  //wait for 1 sec after first data to set zeroo on servo
}

// --- Loop Function ---
void loop() {
  // No need to do anything here for this example.
  // All the action happens in the OnDataRecv callback.
  // You could add other tasks here if needed.
  delay(10); // Small delay to prevent watchdog timer issues if loop is truly empty
}

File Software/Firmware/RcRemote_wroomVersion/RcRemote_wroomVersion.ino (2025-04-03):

#include <esp_now.h>
#include <WiFi.h>
#include <Arduino.h>
#include <HardwareSerial.h>

// --- Configuration ---
// Define the GPIO pins for potentiometers
//const int potPins[] = {17, 18, 3, 4}; //Wroom-S2 version
const int potPins[] = {4, 5, 17, 18, 14, 16}; //Wroom version
const int numPots = sizeof(potPins) / sizeof(potPins[0]);

// Define the GPIO pins for switches
// NOTE: GPIO 35 is INPUT ONLY
//const int switchPins[] = {0, 8, 9, 12, 13, 15, 37}; //WROOM-S2 version
const int switchPins[] = {2, 12, 13, 15, 35, 19}; //WROOM version
const int numSwitches = sizeof(switchPins) / sizeof(switchPins[0]);

// Update frequency (milliseconds)
const unsigned long updateInterval = 100;

// IMPORTANT: Replace with the MAC address of YOUR RECEIVER ESP32
uint8_t receiverMac[] = {0xFF, 0xFF, 0xFF, 0xFF, 0xFF, 0xFF}; // Broadcast placeholder initially
// Example: uint8_t receiverMac[] = {0x3C, 0x71, 0xBF, 0x12, 0x34, 0x56};

// --- Data Structure ---
// Structure to hold sensor data. MUST match the receiver's structure.
typedef struct SensorData {
  uint16_t potValues[numPots];   // Use uint16_t for 12-bit ADC (0-4095)
  bool switchStates[numSwitches]; // true = pressed, false = not pressed
} SensorData;

// Create an instance of the structure
SensorData myData;
//HardwareSerial SerialPort(1);  // UART1 instance

// --- ESP-NOW Variables ---
esp_now_peer_info_t peerInfo;
unsigned long lastUpdateTime = 0;

// --- Callback Function ---
// Function called when data is sent
void OnDataSent(const uint8_t *mac_addr, esp_now_send_status_t status) {

  // Optional: Print confirmation to Sender's Serial Monitor
  // Serial.print("Last Packet Send Status: ");
  // Serial.println(status == ESP_NOW_SEND_SUCCESS ? "Delivery Success" : "Delivery Fail");
}

// --- Setup Function ---
void setup() {
  //SerialPort.begin(115200, SERIAL_8N1, 6, 5); // WROOM-S2
  Serial.begin(115200);
  Serial.println("ESP32 ESP-NOW Sender");

  // 1. Set device as a Wi-Fi Station
  WiFi.mode(WIFI_STA);
  Serial.print("Sender MAC Address: ");
  Serial.println(WiFi.macAddress()); // Print MAC address to help configure receiver

  // 2. Initialize ESP-NOW
  if (esp_now_init() != ESP_OK) {
    Serial.println("Error initializing ESP-NOW");
    return;
  }
  Serial.println("ESP-NOW Initialized.");

  // 3. Register the send callback function
  esp_now_register_send_cb(OnDataSent);

  // 4. Register peer (the receiver)
  memcpy(peerInfo.peer_addr, receiverMac, 6);
  peerInfo.channel = 0; // Use Wi-Fi channel 0 for ESP-NOW
  peerInfo.encrypt = false; // No encryption for simplicity

  // 5. Add peer
  if (esp_now_add_peer(&peerInfo) != ESP_OK) {
    Serial.println("Failed to add peer");
    return;
  }
  Serial.println("Peer Added.");

  // 6. Configure GPIOs
  // Potentiometers (Analog Input) - No specific pinMode needed for ADC1 pins usually
  // Switches (Digital Input with Pull-up)
  for (int i = 0; i < numSwitches; i++) {
    pinMode(switchPins[i], INPUT_PULLUP);
  }
  pinMode(38, INPUT_PULLUP);
  pinMode(40, INPUT_PULLUP);

  Serial.println("GPIOs Configured.");
  Serial.println("Setup Complete. Starting loop...");
}

// --- Loop Function ---
void loop() {
  // Check if it's time to update and send data
  if (millis() - lastUpdateTime >= updateInterval) {
    lastUpdateTime = millis(); // Reset the timer

    // Read Potentiometers
    for (int i = 0; i < numPots; i++) {
      myData.potValues[i] = analogRead(potPins[i]);
      // Optional: Add smoothing/filtering here if needed
    }

    // Read Switches
    for (int i = 0; i < numSwitches; i++) {
      // digitalRead is LOW when pressed (connected to GND) with INPUT_PULLUP
      myData.switchStates[i] = (digitalRead(switchPins[i]) == LOW);
    }

    Serial.println("--- Sent Data ---");
    Serial.print("Pots: ");
    for (int i = 0; i < numPots; i++) {
      Serial.print(myData.potValues[i]);
      if (i < numPots - 1) Serial.print(", ");
    }
    Serial.println();
    Serial.println("---------------------");

    // Send data via ESP-NOW
    esp_err_t result = esp_now_send(receiverMac, (uint8_t *) &myData, sizeof(myData));

    // Optional: Check send result immediately (also handled by callback)
    // if (result == ESP_OK) {
    //   Serial.println("Sent with success");
    // } else {
    //   Serial.print("Error sending the data: ");
    //   Serial.println(esp_err_to_name(result));
    // }
  }
  // Can add a small delay here if needed, but millis() approach is better
  // delay(1); // Small delay to yield CPU if other tasks are running
}

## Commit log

2025-03-25 mods on PCB done
    [CONTROL WIFI ESP32 S3 V4.0-B_Cu.gbr, CONTROL WIFI ESP32 S3 V4.0-B_Mask.gbr, CONTROL WIFI ESP32 S3 V4.0-B_Paste.gbr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]
2025-03-27 powerpoint update
2025-03-30 Servo and ESC working
2025-04-06 forberedelse for drone
    [Joystick.kicad_sch, Lys.kicad_sch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]
